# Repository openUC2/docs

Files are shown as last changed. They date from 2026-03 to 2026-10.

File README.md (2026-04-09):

# openUC2 Documentation

This repository is used to build and deploy openUC2's documentation site.

## Usage

People who are just end-users of openUC2 products & projects should go to [docs.openuc2.com](https://docs.openuc2.com).

Developers should view the current state of the [openUC2/docs](https://github.com/openUC2/docs) repo at [docs-dev.openuc2.com](https://docs-dev.openuc2.com).
That site should be treated as a developer preview which can have disruptive changes without any prior notice; thus, customers should not be sent to `docs-dev.openuc2.com`.

[docs-staging.openuc2.com](https://docs-staging.openuc2.com) should be used as an intermediate "beta preview" version of `docs.openuc2.com`: it is more stable (i.e. has less accidental disruption) compared to `docs-dev.openuc2.com`, but it may still have a few subtle problems which need to be discovered and fixed before the changes are generally exposed to all customers.
It's okay to link certain customers to certain pages in `docs-staging.openuc2.com`, but only if those customers need to have a preview of newer versions of those specific pages before those changes are ready to be made generally available at `docs.openuc2.com`.

For further explanation, please refer to [DN 17](https://www.notion.so/DN-17-Customer-facing-documentation-system-2854e612c78a80a3a1bdcc223bf030c0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).

## Development

### Local preview

Run:

```
npm install
npm run start
```

Then open: <http://localhost:3000>

## Deployment

The openUC2 docs site has three GitHub Pages deployments, each with its own repository:

- development/edge release channel: the `master` branch of [openUC2/docs](https://github.com/openUC2/docs); deploys to [docs-dev.openuc2.com](https://docs-dev.openuc2.com).
- staging/beta release channel: the `staging` branch of openUC2/docs; automatically mirrored to the `deploy` branch of [openUC2/docs-staging](https://github.com/openUC2/docs-staging), which deploys to [docs-staging.openuc2.com](https://docs-staging.openuc2.com)
- prod/stable release channel: the `prod` branch of openUC2/docs; automatically mirrored to the `deploy` branch of [openUC2/docs-prod](https://github.com/openUC2/docs-prod), which deploys to [docs.openuc2.com](https://docs.openuc2.com).

After cloning the openUC2/docs repo, then you can fast-forward your local `staging` and `prod` branches to the desired commits on your local `master` branch.
Then you can deploy changes to the staging and prod release channels by pushing your updated local `staging` and `prod` branches, respectively, up to the openUC2/docs repository.
The deployment process should usually be done as follows:

1. Fast-forward the `staging` branch of the openUC2/docs repo to whichever commit of the `master` branch that we want to publish.
2. Wait for it to build and deploy, then look at `docs-staging.openuc2.com` and fix any problems.
3. Once the version in the `docs-staging` repo is stable and mature enough for publication, fast-forward the `prod` branch of the openUC2/docs repo to the publication-ready commit of the `staging` branch.

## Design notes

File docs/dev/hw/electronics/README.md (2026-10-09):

# Electronics

Boards that run the UC2 ESP32 firmware (`uc2-ESP`). A host talks serial JSON to one board; boards talk CANopen to each other. Protocol, commands and Python clients: [Serial & CANopen interface](../../sw/interface/index.md).

UC2 control topologies

## Available hardware interfaces

| Board | Role | Firmware env | Page |
|---|---|---|---|
| Standalone board v3 / v4 (ESP32 DevKit) | standalone, no CAN | `UC2_3`, `UC2_4` | [Standalone board](./uc2-standalone-board/README.md) |
| Standalone board v4 | CAN master, node 1 (hybrid: motors local, LED/galvo via CAN) | `UC2_canopen_standalone_v4_release` | [Standalone board](./uc2-standalone-board/README.md) |
| HAT+ for Raspberry Pi 5 | CAN master, node 1 | `UC2_canopen_master` | [HAT+](./hat-plus/README.md): [v1](./hat-plus/v1/README.md), [v2](./hat-plus/v2/README.md) |
| Stepper backpack (XIAO ESP32-S3) | CAN satellite, motor A/X/Y/Z = node 10/11/12/13 | `UC2_canopen_slave_motor` | [Stepper backpack](./stepper-backpack/README.md) |
| Laser interface (XIAO ESP32-S3) | CAN satellite, node 20 | `UC2_canopen_slave_laser` | [FRAME electronics](./frame/README.md#laser-interface) |
| LED / illumination (XIAO) | CAN satellite, node 30 | `UC2_canopen_slave_led` | [Boards & node IDs](../../sw/interface/reference/boards-and-node-ids.md) |
| Galvo interface (XIAO) | CAN satellite, node 40 | `UC2_canopen_slave_galvo` | [Boards & node IDs](../../sw/interface/reference/boards-and-node-ids.md) |
| PS4 controller | Bluetooth on standalone builds, or CAN bridge node 5 (DS4 on USB-OTG) | `UC2_canopen_bridge_ps4_usbhost` | [PS4 controller](./ps4-controller/README.md) |

[FRAME electronics](./frame/README.md) is the design reference for the HAT+, stepper backpack Rev C, laser interface and pogo-pin connectors.

Every board also accepts serial JSON on its own USB port: 115200 baud on the standalone board, 921600 on the HAT+ ESP32, USB-CDC (baud ignored) on XIAO satellites.

## Bus

| Item | Value |
|---|---|
| Protocol | CANopen (CANopenNode), master = node 1 |
| Bitrate | 500 kbit/s, fixed |
| Connector | JST-XH 4, daisy-chained: **1 GND, 2 +12 V, 3 CAN_H, 4 CAN_L** |
| Transceiver | SN65HVD230 (3.3 V), not isolated |
| Termination | 120 Ω at the two physical ends of the bus only |

Termination solder jumpers, all open by default:

| Board | Jumper |
|---|---|
| HAT+ v2 | JP801 |
| HAT+ v1 | JP1001 |
| Stepper backpack | JP502 |
| Laser interface | JP301 |
| Galvo interface | JP2001 |

Pins, node IDs and routing per env: [Boards, roles & node IDs](../../sw/interface/reference/boards-and-node-ids.md). Adding a board to the bus: [Add a CAN satellite](../../sw/interface/how-to/add-can-satellite.md).

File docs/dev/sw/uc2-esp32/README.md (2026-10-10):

---
title: Firmware
---

# UC2-ESP32 Firmware

One firmware ([youseetoo/uc2-esp32](https://github.com/youseetoo/uc2-esp32), branch `main`) runs on every UC2 ESP32 board. Each board has its own PlatformIO environment that selects pins and modules at compile time. A build runs in one of three roles:

| Role | Example env | What it does |
|---|---|---|
| Standalone | `UC2_3`, `UC2_4` | JSON over USB serial, all devices on the board |
| CAN master | `UC2_canopen_master` (HAT+) | JSON over USB serial, routes each device locally or over CANopen to a satellite |
| CAN satellite | `UC2_canopen_slave_motor`, `_laser`, `_led`, … | executes commands from the master; still accepts JSON on its own USB port |

All envs, node IDs and baud rates: [Boards, roles & node IDs](../interface/reference/boards-and-node-ids.md).

## Where the code lives

| Path | Content |
|---|---|
| `platformio.ini` | one `[env:…]` per board, with `-D` feature flags |
| `main/config/<env>/PinConfig.h` | pins and defaults of that board |
| `main/src/<module>/` | controllers (`motor`, `home`, `laser`, `led`, `scanner`, `tmc`, `bt`, …), `serial/` (JSON parser, `Endpoints.h`), `canopen/` |

## Build and flash

- Prebuilt images: web flasher at [youseetoo.github.io/flasher.html](https://youseetoo.github.io/flasher.html) (Chrome or Edge, USB).
- From source: `pio run -e <env> -t upload`. Details: [Compiling from scratch](./08_Flashing_the_firmware.md).
- Satellites on a CAN bus can be updated through the master: [Update firmware over CAN](../interface/how-to/update-firmware-over-can.md).

## Talk to it

- [Serial & CANopen interface](../interface/index.md): overview and tutorials
- [Serial protocol](../interface/reference/serial-protocol.md): framing, `qid`, replies
- [Serial commands](../interface/reference/serial-commands.md): all endpoints with keys and examples

## Pages in this folder

- [Build environment](./01_Setup_Buildenvironment.md)
- [Firmware description](./02_UC2_Firmware_Description.md): architecture and modules
- [Controlling the UC2e](./07_Controling_the_ESP32.md): clients (Python, web, PS4, ImSwitch)
- [UC2Serial Android app](./07_Controlling_the_ESP32_APP.md)
- [Compiling from scratch](./08_Flashing_the_firmware.md)

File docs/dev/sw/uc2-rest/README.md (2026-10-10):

---
title: Hardware Control API
---

# UC2-REST Python API

:::warning Outdated
Most of the API shown here does not exist in `uc2rest`. Current documentation: [uc2rest reference](../interface/reference/python-uc2rest.md).
:::

Advanced documentation for the UC2-REST Python library, including API reference, integration guides, and custom development.

## Overview

UC2-REST is the Python interface library that provides high-level control of UC2 hardware through the UC2-ESP32 firmware. It serves as the bridge between Python applications (including ImSwitch) and the low-level hardware control.

## Key Features

- **Object-Oriented API**: Intuitive Python interface for hardware control
- **Dual Communication**: USB Serial and WiFi/HTTP support
- **Error Handling**: Robust communication with automatic retry
- **ImSwitch Integration**: Native support for ImSwitch microscopy software
- **Extensible**: Easy to add custom device managers and protocols

## Available Documentation

### Getting Started
- **Installation Guide** - Install UC2-REST library
- **Quick Start** - Basic usage examples
- **API Overview** - High-level API introduction

### Core Documentation
- **[Communication Introduction](./06_INTRO.md)** - Basic communication concepts
- **[ESP32 Messaging](./ESP32_Messaging_Callback.md)** - Message handling system
- **[Motor Control](./ESP32_Motor.md)** - Motor control examples
- **[Command Sending](./05_Sending_Commands.md)** - Command interface details

### Advanced Topics
- **API Reference** - Complete API documentation
- **Integration Guide** - Integrate with other software
- **Custom Managers** - Create custom device managers
- **Protocol Documentation** - Communication protocol details

## Quick Reference

### Basic Connection
```python
from UC2REST import UC2Client

# USB Serial connection
client = UC2Client(serialport="/dev/ttyUSB0")

# WiFi connection
client = UC2Client(host="192.168.1.100", port=31950)

# Check connection
if client.is_connected:
    print("Connected to UC2-ESP32")
```

### Hardware Control
```python
# LED control
client.led.set_led(channel=1, intensity=100)
client.led.set_led_array([100, 50, 75, 0])

# Motor control
client.stage.move_x(1000)
client.stage.move_xyz(x=500, y=500, z=100)
client.stage.home_xyz()

# Laser control
client.laser.set_laser(channel=1, intensity=50)
client.laser.turn_off_all()

# Sensor reading
sensors = client.sensor.get_sensor_data()
position = client.stage.get_position()
```

## Architecture

### Class Hierarchy
```
UC2Client
├── SerialManager (USB communication)
├── HTTPManager (WiFi communication)
├── LEDManager (LED control)
├── StageManager (Motor control)
├── LaserManager (Laser control)
├── SensorManager (Sensor reading)
└── StateManager (System status)
```

### Communication Flow
```
Python Application
      ↓
   UC2Client
      ↓
Communication Manager (Serial/HTTP)
      ↓
JSON Protocol
      ↓
UC2-ESP32 Firmware
      ↓
Hardware Components
```

## Device Managers

### LED Manager
```python
class LEDManager:
    def set_led(self, channel, intensity):
        """Set individual LED intensity"""

    def set_led_array(self, intensities):
        """Set multiple LED intensities"""

    def get_led_status(self):
        """Get current LED status"""
```

### Stage Manager
```python
class StageManager:
    def move_x(self, steps):
        """Move X axis by specified steps"""

    def move_xyz(self, x=0, y=0, z=0):
        """Move multiple axes simultaneously"""

    def set_position(self, x=None, y=None, z=None):
        """Set absolute position"""

    def home_xyz(self):
        """Home all axes"""

    def get_position(self):
        """Get current position"""
```

### Laser Manager
```python
class LaserManager:
    def set_laser(self, channel, intensity):
        """Set laser power"""

    def turn_off_all(self):
        """Emergency laser shutdown"""

    def get_laser_info(self):
        """Get laser capabilities"""
```

## Integration Examples

### ImSwitch Configuration
```json
{
  "rs232devices": {
    "ESP32": {
      "managerName": "ESP32Manager",
      "managerProperties": {
        "serialport": "/dev/ttyUSB0",
        "host_": "192.168.1.100"
      }
    }
  },
  "positioners": {
    "ESP32Stage": {
      "managerName": "ESP32StageManager",
      "managerProperties": {
        "rs232device": "ESP32"
      },
      "axes": ["X", "Y", "Z"],
      "forScanning": true
    }
  }
}
```

### Custom Device Manager
```python
from UC2REST import UC2Client
from imswitch.imcontrol.model.interfaces import DeviceManager

class CustomUC2Manager(DeviceManager):
    def __init__(self, deviceInfo, name, **kwargs):
        super().__init__(deviceInfo, name, **kwargs)

        # Initialize UC2-REST client
        self.client = UC2Client(
            serialport=deviceInfo.managerProperties.get("serialport"),
            host=deviceInfo.managerProperties.get("host"),
        )

    def custom_function(self, parameters):
        """Implement custom functionality"""
        return self.client.send_command(
            {"task": "/custom_act", "parameters": parameters}
        )
```

### Jupyter Notebook Integration
```python
# Interactive microscopy control
import ipywidgets as widgets
from IPython.display import display

def create_motor_controls(client):
    """Create interactive motor controls"""

    # Movement buttons
    move_x_plus = widgets.Button(description="X+")
    move_x_minus = widgets.Button(description="X-")

    # Step size slider
    step_size = widgets.IntSlider(value=100, min=10, max=1000)

    def on_move_x_plus(b):
        client.stage.move_x(step_size.value)

    def on_move_x_minus(b):
        client.stage.move_x(-step_size.value)

    move_x_plus.on_click(on_move_x_plus)
    move_x_minus.on_click(on_move_x_minus)

    return widgets.VBox([step_size, widgets.HBox([move_x_minus, move_x_plus])])

# Create and display controls
controls = create_motor_controls(client)
display(controls)
```

## Advanced Usage

### Error Handling
```python
from UC2REST import UC2RESTError
import serial

try:
    client = UC2Client(serialport="/dev/ttyUSB0")
    client.stage.move_x(1000)

except UC2RESTError as e:
    print(f"UC2-REST error: {e}")

except serial.SerialException as e:
    print(f"Serial communication error: {e}")

except Exception as e:
    print(f"Unexpected error: {e}")
```

### Custom Commands
```python
def send_custom_command(client, command_data):
    """Send custom JSON command"""
    try:
        response = client.send_command(command_data)

        if response.get("return") == 1:
            return response
        else:
            raise UC2RESTError(f"Command failed: {response}")

    except Exception as e:
        print(f"Communication error: {e}")
        return None

# Example usage
result = send_custom_command(
    client, {"task": "/custom_task", "parameter1": "value1", "parameter2": 42}
)
```

### Performance Optimization
```python
class OptimizedController:
    def __init__(self, client):
        self.client = client
        self.position_cache = {"x": 0, "y": 0, "z": 0}

    def move_relative(self, dx=0, dy=0, dz=0):
        """Move relative with position caching"""
        # Update cached position
        self.position_cache["x"] += dx
        self.position_cache["y"] += dy
        self.position_cache["z"] += dz

        # Send movement command
        self.client.stage.move_xyz(x=dx, y=dy, z=dz)

    def get_cached_position(self):
        """Get position from cache (faster than querying hardware)"""
        return self.position_cache.copy()

    def sync_position(self):
        """Synchronize cache with actual hardware position"""
        actual_pos = self.client.stage.get_position()
        self.position_cache.update(actual_pos)
        return actual_pos
```

## Custom Protocol Development

### Protocol Extension
```python
class CustomProtocol:
    def __init__(self, client):
        self.client = client

    def batch_commands(self, commands):
        """Execute multiple commands efficiently"""
        batch_command = {"task": "/batch_act", "commands": commands}
        return self.client.send_command(batch_command)

    def stream_data(self, duration, interval):
        """Stream sensor data for specified duration"""
        stream_command = {
            "task": "/stream_start",
            "duration": duration,
            "interval": interval,
        }

        # Start streaming
        response = self.client.send_command(stream_command)

        if response.get("return") == 1:
            # Read streamed data
            data = []
            for _ in range(int(duration / interval)):
                reading = self.client.sensor.get_sensor_data()
                data.append(reading)
                time.sleep(interval)

            return data
        else:
            raise UC2RESTError("Failed to start data streaming")
```

## Testing and Validation

### Unit Tests
```python
import unittest
from UC2REST import UC2Client

class TestUC2REST(unittest.TestCase):
    def setUp(self):
        self.client = UC2Client(serialport="/dev/ttyUSB0")

    def test_connection(self):
        """Test basic connection"""
        self.assertTrue(self.client.is_connected)

    def test_led_control(self):
        """Test LED control"""
        # Turn LED on
        self.client.led.set_led(channel=1, intensity=100)

        # Turn LED off
        self.client.led.set_led(channel=1, intensity=0)

        # Test should not raise exceptions
        self.assertTrue(True)

    def test_stage_movement(self):
        """Test stage movement"""
        original_pos = self.client.stage.get_position()

        # Move and return
        self.client.stage.move_x(100)
        time.sleep(1)
        self.client.stage.move_x(-100)
        time.sleep(1)

        final_pos = self.client.stage.get_position()

        # Should return to approximately original position
        self.assertAlmostEqual(original_pos["x"], final_pos["x"], delta=10)

if __name__ == "__main__":
    unittest.main()
```

### Performance Benchmarks
```python
import time
import statistics

def benchmark_communication_speed(client, n_commands=100):
    """Benchmark communication speed"""
    times = []

    for _ in range(n_commands):
        start = time.time()
        client.state.get_state()
        end = time.time()
        times.append(end - start)

    return {
        "mean": statistics.mean(times),
        "median": statistics.median(times),
        "stdev": statistics.stdev(times),
        "commands_per_second": 1.0 / statistics.mean(times),
    }

# Run benchmark
results = benchmark_communication_speed(client)
print(f"Communication speed: {results['commands_per_second']:.1f} commands/sec")
```

## Troubleshooting

### Common Issues

**Connection Problems**:
```python
# Check available serial ports
import serial.tools.list_ports

ports = serial.tools.list_ports.comports()
for port in ports:
    print(f"{port.device}: {port.description}")

# Test with different parameters
try:
    client = UC2Client(serialport="/dev/ttyUSB0", baudrate=115200, timeout=2.0)
except Exception as e:
    print(f"Connection failed: {e}")
```

**Communication Timeouts**:
```python
# Increase timeout for slow operations
client = UC2Client(serialport="/dev/ttyUSB0", timeout=5.0)

# Implement retry logic
def robust_command(client, command_func, max_retries=3):
    for attempt in range(max_retries):
        try:
            return command_func()
        except Exception as e:
            if attempt == max_retries - 1:
                raise e
            time.sleep(1)
```

**Debug Mode**:
```python
# Enable debug output
client = UC2Client(serialport="/dev/ttyUSB0", DEBUG=True)

# All communication will be logged
client.stage.move_x(1000)
# Output: [DEBUG] Sending: {"task": "/motor_act", ...}
#         [DEBUG] Received: {"return": 1, ...}
```

## Contributing

### Development Setup
```bash
# Clone repository
git clone https://github.com/openUC2/UC2-REST
cd UC2-REST

# Install in development mode
pip install -e .

# Install development dependencies
pip install -r requirements-dev.txt
```

### Code Style
- Follow PEP 8 style guidelines
- Use type hints where possible
- Document all public methods
- Include docstring examples

### Testing
```bash
# Run unit tests
python -m pytest tests/

# Run with coverage
python -m pytest --cov=UC2REST tests/

# Run integration tests (requires hardware)
python -m pytest tests/integration/
```

## Related Resources

- **[UC2-ESP32 Firmware](../uc2-esp32/README.md)** - Firmware documentation
- **[ImSwitch Integration](../imswitch/Advanced/02_Usage/UC2-REST.md)** - ImSwitch usage guide
- **[Hardware Interfaces](../../hw/electronics/README.md#available-hardware-interfaces)** - Hardware components

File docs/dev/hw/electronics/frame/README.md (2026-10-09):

# FRAME

Development repository for electronic parts of the mAIkroscope (formerly fiveD/XYZ)

## CANBUS as communication between devices

CANBUS is a differential bus where many devices are connected to the same CAN_H and CAN_L wires, then can communicate with each other.

The electrical functionality requires a dedicated CAN transceiver chip for every device connecting to the bus. The receiver converts differential signaling on the bus to input and output interfaces, while providing tolerance to voltages of commonly 20V on the CAN_H/CAN-L and isolating faulty voltages from reaching to the GPIOs of connected controllers.

The two wires of CANBUS need to be connected together with two 120 Ohm resistors at opposite ends. This termination is like impedance matching and prevents the signals to reflect back from a far end of the bus wires. The terminators should be placed on the ends that are farthest apart, and can probably be integrated on PCBs of the devices that are farthest apart. The "backbone" with the termination on both ends should be much longer than the taps ("stubs") from the backbone to the devices. The physical wires, electrical specs (like differential signaling and voltage levels) are OSI layer 1.

CAN message collision avoidance is done in a CAN controller. This is available as a separate chip (with SPI interface), but it is also integrated as peripheral in the ESP32. At the start of each frame, every device wanting to send something starts sending their CAN ID (programmed into the device, must be unique). If a device has a lower ID, it gets priority by sending a dominant bit (logical 0, CAN_H and CAN_L are driven to different voltage levels) where other devices send a logical 1 (recessive bit, CAN_H and CAN_L are not driven making them return to equal voltage). If a device with a higher ID gets overruled this way, it will listen in this frame cycle and waits for the next frame to start before attempting to transmit its ID again. The frames also contain set amount of data and error checking bits.

There are frame types to request data (Remote frame), data containing (data frame), errror frame (when error is detected) and overload frame (indicating delay between data or remote frames is needed).

That is Link Layer (OSI layer 2).

OSI Layers 1 and 2 as implemented are standardized with ISO 11898-1.

ESP32 calls their implementation of this and maybe higher OSI layers TWAI: [ESP-IDF TWAI Docs](https://docs.espressif.com/projects/esp-idf/en/v4.2.1/esp32/api-reference/peripherals/twai.html)

ESP32 CAN controller is not compatible with CAN FD (flexible data-rate), just classical CAN with 11-bit IDs (Standard Frame Format) and 29-bit IDs (Extended Frame Format).

The ESP32 TWAI controller depends on getting a receiving signal at the same time that it is sending something in order to work, because that is how it can determine if it is allowed to talk (CAN ID arbitration/priorities).

UC2 runs CANopen (CANopenNode) on top at 500 kbit/s, with the ESP32 master as node 1 and satellites as slaves: [Architecture](../../../sw/interface/explanation/architecture.md), [Boards, roles & node IDs](../../../sw/interface/reference/boards-and-node-ids.md).

## hatplus-for-raspberrypi-5

- [HAT schematic PDF (Rev D)](../hat-plus/v1/schematic.pdf)
- <a href={require("../hat-plus/v2/ibom-hatv2.html")} target="_blank">v2 HAT ibom HTML</a>

This board is effectively the mainboard for the mAIkroscope. It contains DC power input for the whole machine, switched power transmission to all motors, main coordinating microcontroller and interfacing with a Raspberry Pi.

The HAT is put on top of a Raspberry Pi 5 and can supply it with 5.1V 5A through the 40-pin header. The HAT will also fit on a NVIDIA Jetson development board, because its 40-pin header is designed to be compatible with Raspberry Pi's.

There are many comments for design choices, mechanisms, failsafes and links to external ressources in the [HAT schematic PDF](../hat-plus/v1/schematic.pdf).

The microcontroller is a ESP32-WROOM-32E-N8 module with integrated PCB antenna, 8 MB flash. The used ESP32-D0WD-V3 chip in the module has 449 KB ROM, 520 KB SRAM and 16 KB SRAM in RTC core.

### Raspberry Pi HAT+ implementation (EEPROMS, HAT+ spec)

Our HAT is designed to comply with [Raspberry Pi HAT+ specifications](https://datasheets.raspberrypi.com/hat/hat-plus-specification.pdf).

However, it has the function of 2 types of HAT+s: Power supply and using the GPIO header for data exchange purposes.

The I2C addresses of EEPROMS on the HAT indicate the HAT+ class to the Raspberry Pi firmware. In multiple HAT+ stacked on one Raspberry Pi, there can be only one HAT of each class per spec and to avoid I2C address collisions.

The HAT has 2 EEPROM chips with functions and content:

| I2C Address | HAT+ class meaning | EEPROM contents |
| --- | --- | --- |
| 0x1010_000  | Standard (uses GPIO for data) | tbd |
| 0x1010_000  | Power: MODE1 (can deliver 5A) | tbd |

The content of the HAT can be custom content like serial numbers, manufacturer, or drivers/instructions for the Raspberry Pi OS on how to interface with the HAT. The format and mandatory fields are in the Raspberry Pi HAT+ spec document.

For our HAT, it would make sense to fill the EEPROMS for these functions:

- Ensure that the full power for USB devices is automatically activated (implementing a MODE1 HAT+).
- Add our company name, product name, board revision, unique serial number that we keep track of in the company
- Driver or interface/pin description to make the SPI CAN controller chip (MCP2515) available to python scripts via Linux.
- Descriptions of other GPIO pin functions, to be able to use them abstractly in future scripts: buspower_EN, ESP32 interface UART and flashing, etc
- Maybe things like hardware configuration options that should "just work", like what features and modules the mAIkroscope model has that it is built into, and factory calibration data for its modules

### Raspberry Pi pinout

For Raspberry Pi pin numbering and assignable or fixed functions, see [pinout.xyz](https://pinout.xyz).

In the table is the physical/board pin number, not GPIO number. The pin numbering on the header is odd-even.

| RPi | Function |
| --- | --- |
| 3 | I2C-1_SDA connectable to ESP and XH_5V+I2C via solderjumper JP101  |
| 5 | I2C-1_SCL connectable to ESP and  XH_5V+I2C via solderjumper JP102 |
| 8 | UART_TX to ESP, 921600 baud (parallel with USB-UART TX) |
| 10  | UART_RX from ESP (parallel with USB-UART RX) |
| 11  | ESP Auto-program circuit RTS |
| 16  | buspower-off when HI |
| 19  | CAN-Controller SPI PICO |
| 21  | CAN-Controller SPI POCI |
| 23  | CAN-Controller SPI SCK |
| 24  | CAN-Controller SPI CS |
| 26  | EEPROM I2C SCL (GPIO7; the HAT+ spec puts ID_SC on pin 28) |
| 27  | EEPROM I2C SDA (ID_SD, GPIO0) |
| 32  | CAN-Controller Interrupt |
| 36  | ESP Auto-program circuit DTR |

### ESP32 pinout

Actual chosen model is ESP32-WROOM-32E-N8.

It runs the CAN master firmware (env `UC2_canopen_master`, node 1, serial 921600 baud). It is programmable via the USB-C port and CP2102 USB-Serial chip, or via Raspberry Pi UART (manual press of BOOT and RST necessary, or programming of the 2 Raspberry Pi GPIO to use the Auto-program circuit).

In the table are only GPIOs that are used and notable for the HAT. All GPIOs are also available at testpoints.

| GPIO | Function |
| ---- | --- |
| 4 | Buspower_off when HI |
| 17 | CAN/TWAI TX (send) |
| 18 | CAN/TWAI RX (receive) |
| 19 | Neopixel LED data |
| 21 | I2C-1_SDA to XH_5V+I2C connector and solderjumpable to Raspi |
| 22 | I2C-1_SCL to XH_5V+I2C connector and solderjumpable to Raspi |
| 27 | Camera-IO-interface Cam In Line 0 |
| 32 | Camera-IO-interface Cam Out Line 1 |
| 33 | Camera-IO-interface Cam In/Out Line 2 |

### Emergency STOP connector

There is a 3.5 mm TRS connector (stereo headphones) to connect an external box with a Emergency-STOP button and LEDs (optional). It is J501 and oriented out the back of the mAIkroscope.

A STOP button should be normally closed, and should open and lock when pressed. This button should be connected between Tip and Ring of the TRS connector. This button is required for Buspower (5V or 12V out of the respective XH jacks) to turn on.

LEDs can be placed in or on the external box so it is easily visible in dark conditions. The LEDs have a budget of 3.3V and 20 mA, and resistors should be included in the box. If more amperage is pulled, the HAT may recognize it as STOP button press. Connect LEDs with High side at Tip and Low side at Sleeve of TRS connector. LEDs will always be lit regardless of STOP button state.

### HAT: Terminating CANBUS or activating CAN activity indicator LED

Close JP jumpers by making a solder bridge between the 2 pads. To open a NO (normally open) solderjumper again, wipe, wick or suck away the solder bridge. To open a NC (normally closed) solderjumper, cut the trace between the pads with a knife very carefully and not cutting too deep. Design flaw: Cutting too deep exposes the copper of the inner layers and may cut or short traces on the inner layers. The cut should be planned in the PCB editor, and the trench should be cleaned up and filled with solder mask after cutting. In future, use 0-Ohm resistors for NC.

| Operation | Effect |
| --- | --- |
| Close JP1001 | Terminates CANBUS on the board by connecting CAN_H and CAN_L through 120 Ohm resistor (v2: JP801) |
| Close JP1002 | Red LED D1001 lights when CAN bus is in dominant state (logical 0, lines at different voltages) (v2: JP802) |

### Disabling communication or power-switching functions

This is only relevant for troubleshooting and may defeat safety functions.

| Operation | Effect |
| --- | --- |
| Close JP201 | ESP and Raspberry Pi can no longer turn off buspower via GPIO pin |
| Close JP601 | Override all buspower-off sources including Emergency-STOP button. Button SW601 can still momentary turn-off buspower. |
| Open JP901  | Disconnect Raspberry pin from RTS line of CP2102 and Auto-program circuit |
| Open JP902  | Disconnect Raspberry pin from DTR line of CP2102 and Auto-program circuit |

## stepper-backpack

Schematic PDF: `kicad/stepper-backpack/OUTPUTS/for-humans/stepper-backpack.pdf`

ibom HTML: `kicad/stepper-backpack/OUTPUTS/for-humans/ibom.html`

stepper-backpack is a PCB to fasten to the back of a NEMA 11 stepper motor. It enables the motor-PCB-assembly to be controlled via CAN with high-level commands and implements absolute feedback.

- Glue a circular magnet to the end of the stepper motor's axle
- Mount the PCB to the back of the motor using 3 pcs of M2.5 screws with cylindrical standoffs between board and motor. The standoffs should be about 2.5mm long. The PCB should fit completely behind the motor.
- Connect the motor's electrical connections (coils) to the PCB via screw terminal blocks. A and B labels correspond to the 2 coils in the motor.
- Connect it to a 12V supply and CAN via JST XH 4-pin connector (1 GND, 2 +12 V, 3 CAN_H, 4 CAN_L)
- Firmware env `UC2_canopen_slave_motor`; default node 11, CI builds `_motA/_motX/_motY/_motZ` = nodes 10/11/12/13 (details: [Stepper backpack](../stepper-backpack/README.md))
- The PCB controls the motor with a TMC2209 stepper motor driver
- A magnetometer on the PCB measures axle position and supply feedback for accurate positioning
- A XIAO ESP32S3 plugged in to the PCB can accept high-level commands (go to a position) and handle autonomous homing and stepping control (low level control of the stepper motor driver)
- The high-level interface can supply information about motor load, command success/status, fail state, etc.
- Endstop can be connected to a XIAO pin, 3.3V and GND with JST ZH 3-pin connector.

### Pinout

The different XIAO models connect to different ESP GPIOs, and strapping pins, pins with glitches or pins with default pullups/pulldowns may be different between ESP models in the XIAO format.

| XIAO pin | Function |
| --- | --- |
| D0 | Endstop |
| D1 | CAN Receive / SCL on old bus |
| D2 | CAN Send / SDA on old bus |
| D3 | Motor driver DIAG output |
| D4 | I2C SDA to encoder |
| D5 | I2C SCL to encoder |
| D6 | UART send to motor driver |
| D7 | UART recv from motor driver  |
| D8 | Motor direction |
| D9 | Motor step |
| D10 | Motor driver enable |

### Current sensing and current setting

Rsense (or R_SENSE) is __0.2 Ohm__. This is the value of the sense resistance connected to BRA and BRB of the TMC2209.

The current limit can be set by setting the __Vsense__ value in the TMC, which is the sensitivity of the current measurement. Setting this, with the 0.2 Ohms of actual resistance on stepper-backpacker, yields:

- Vsense=0 (low sensitivity curr sense setting): 1.4A peak, 1A RMS
- Vsense=1: 0.8A peak, 0.55A RMS

### Converting Rev. C from 12V+CAN to 5V+I2C

Make sure there are pullups (4.7k) to 3.3V somewhere on both I2C lines.

Use the ibom.html to find the correct solderjumpers on the board.

Close JP jumpers by making a solder bridge between the 2 pads. Open R 0-resistors by unsoldering them or snapping them with pliers.

| Operation | Effect |
| --- | --- |
| Close JP102 | CANBUS_P connects directly to XIAO GPIO (as I2C-1_SDA) |
| Close JP103 | CANBUS_N connects directly to XIAO GPIO (as I2C1_SCL) |
| Close JP501 | Connects CAN transceiver Rs to 3.3V to STBY transmitter driver |
| Open R502 | Disconnect still-active CAN receiver oupoutput from XIAO pin D1 |
| Open R501 | Disconnects CAN transceiver VCC power input from 3.3V |
| Close JP101 | Connects 12V and 5V power nets (Warning: Do not connect 12V when closed) |

### Terminating CANBUS or activating CAN activity indicator LED

| Operation | Effect |
| --- | --- |
| Close JP502 | Terminates CANBUS on the board by connecting CAN_H and CAN_L through 120 Ohm resistor |
| Close JP503 | Red LED D501 lights when CAN bus is in dominant state (logical 0, lines at different voltages) |

## Laser-interface

This board can control a laser or LEDs and has 4 channels. It connects to the XH_12V+CAN backbone, has a XIAO to accept CAN commands and generate PWM signals, and has connectors for interlock sources. The interface to the laser is 4x PWM signal between 0V and 3.3V (LO should mean off), and 12V power.

Firmware env `UC2_canopen_slave_laser`, default node 20; laser channels 0–3 map to OD sub-index 1–4.

### XIAO pinout

I is intended as input to the XIAO. O is intended as output.

| XIAO pin | XIAO ESP32S3 pin | Board Function |
| --- | --- | --- |
| D0 | GPIO_01 | I: LO when interlock tripped (enable pullup), O: pull LO to light keyswitch-LED |
| D1 | GPIO_02 | O: signal_1 |
| D2 | GPIO_03 | O: signal_2 |
| D3 | GPIO_04 | O: CAN-SEND |
| D4 | GPIO_05 | O: signal_3 |
| D5 | GPIO_06 | O: signal_4 |
| D6 | U0TXD/GPIO_43 | Unused, available on J1101 |
| D7 | U0RXD/GPIO_44 | Unused, available on J1101 |
| D8 | GPIO_07 | Unused, available on J1101 |
| D9 | GPIO_08 | I: LO when interlock has power (keyswitch in ON position) |
| D10 | GPIO_09 | I: CAN-RECV |

### Keyswitch specifications and connections

J102 is a 3-pin screw terminal to connect a key-switch and a red LED.

The key-switch should be a single-pole single-throw key-operated switch where the key can only be removed in OFF position. It switches less than 1 mA at 3.3V. In the ON position, the switch should connect pin 2 and 3 of J102.

The LED indicates when the interlock has triggered and the user needs to reset the interlock by turning off and on the keyswitch. It has 200 Ohms in series at 3.3V, so a red LED will be driven with around 7 mA. An ESP GPIO can light this LED at half current. The red LED on the board close to the output terminal has the same states as the external LED. An LED should directly be connected to J102 with Anode (+) on pin 2, and Cathode (-) on pin 1.

### Interlock

The interlocks ensure that a signal can only pass from the ESP to the laser if:

- The keyswitch is in the ON position
- 12V power is stable (aka Emergency-stop not pushed)
- A magnet switch is closed indicating that something like a laser-safety hood is covering the device
- An endstop or optical endstop is pressed indicating that the modules are fully inserted, the hood is closed, etc.

#### Interlock behavior and status inticators

The interlock has to be powered on by turning the keyswitch ON. It will then watch all the interlock sources, and trigger if one of the sources has an unsafe state.

If the interlock has been triggered, it will stop transmitting any signal to the laser, and the red LED by the keyswitch and by the output terminals will be lit. The interlock will stay triggered until it is reset by turning the keyswitch OFF and ON again.

If the interlock is active and not triggered, signals from the ESP (signal_1-4) will be transmitted to the output terminal block. Probably only binary signals like PWM will work. If the interlock is transmitting, the green LED by the output terminals will be lit, but the red LED next to it will not be lit.

#### Interlock sources

__Keyswitch (J102)__: The keyswitch switches power to the latch circuit of the signals interlock. If this is ON, the green LED close to the output terminals will be lit.

__12V-OK (internal)__: The 12V input has to stay above 11.3V. If power falls below that, the 12V power to the laser will be turned off, and the interlock for the signals will be triggered. This enables early detection when the Emergency Stop has been pressed and the power is interrupted. When the 12V to the laser is ON, the green LED below the XIAO will be lit.

__Endstop (J103)__: The 3-pin screw terminal J103 provides GND, signal, and 3.3V. The signal has to be HI for normal operation, like when the modules are fully inserted or when the safety hood is closed. If the signal pin is LO or floating, it will trigger the interlock. Because there is constant 3.3V and GND available, optical endstops can be used.

__Magnet Switch (J104)__: On the 2-pin screw terminal J104, a simple magnet switch (reed switch) or other simple switch can be connected. The switch should close in the presence of a magnet, and be open otherwise. For normal operation, a magnet can be fixed to the safety hood, and the switch in the base where the magnet will be close if the hood is closed (safe). Other switches can also be used. When the contacts are closed (shorted), it is safe, and when the switch is opened, the interlock triggers.

#### Interlock overrides

Parts of the interlock can be deactivated so that no condition at this interlock source will trigger the interlock. This way, the laser-interface can be configured to the types of safety devices available, when it is integrated into a microscope.

To override parts of the interlock, turn on one or multiple switches inside the dipswitch __SW701__ to the side labeled ON. This will close the switch and assume SAFE regardless of the actual state of the interlock source. No state on the respective interlock source will trigger the interlock.

The individual switches of the dipswitch are numbered. All interlock sources are active if all switches are OFF (set to the side opposite of the side labeled ON).

| SW701 switch number | effect when ON |
| --- | --- |
| 1 | Magnet switch J104 overridden |
| 2 | 12V-OK interlock triggering overridden and 12V output to laser always ON |
| 3 | Hood Endstop switch J103 overridden |
| 4 | Overrides whole interlock including keyswitch. Signals will always be passed, but 12V-OK still switches laser power |

### Solderjumpers

| Operation | Effect |
| --- | --- |
| Close JP301  | Terminates CANBUS on the board by connecting CAN_H and CAN_L through 120 Ohm resistor |
| Close JP302  | Red CAN LED lights when CAN bus is in dominant state (logical 0, lines at different voltages) |
| Close JP1101 | Add 4.7k pullup on D6 |
| Close JP1102 | Add 4.7k pullup on D7 |
| Close JP1103 | Add 4.7k pullup on D8 |

### Using the board as CAN-to-GPIO converter

J1101 is a 9-pin screw terminal connected to the ESP/XIAO pins (before the interlocks), 12V and GND. The 12V is not switched. Signals 1-4 have always-connected pulldown resistors, D6-D8 have optional pullup resistors that can be enabled by closing solderjumpers.

| Screw terminal pin | connection  | pullup/pulldown |
| --- | --- | --- |
| 1 | GND | |
| 2 | 12V | |
| 3 | D1/signal_1 | down 4.7k |
| 4 | D2/signal_2 | down 4.7k |
| 5 | D4/signal_3 | down 4.7k |
| 6 | D5/signal_4 | down 4.7k |
| 7 | D6 | up 4.7k when closing JP1101 |
| 8 | D7 | up 4.7k when closing JP1102 |
| 9 | D8 | up 4.7k when closing JP1103 |

## Pogopin-connectors

Pogo pins are spring-loaded contacts. They will enable a module to automatically make electrical connections to the mainboard when it is inserted into the microscope.

- The boards have to be worked on in pairs so that the pins (M) align with the contact pads (F) and have the expected pinout.
- The boards need to be pressed and held together for the pins to make proper contact. The datasheet of the used pins specifies their optimal/minimum/maximum depress distance and spring force.
- The pogo pins have a current capibility of 1A per pin. For power transmission 12V is used over the pins and converted down (DC-DC converter) on the board with the device that needs it.
- In the original design I2C was passed via the pins, with the module as I2C peripheral of the mainboard. Current satellites use CAN instead, on JST-XH 4: GND, +12 V, CAN_H, CAN_L.
- The pogo pins can break off easily if the tips experience force to the sides. The pins should therefore be protected.  They can be placed in the part inside the microscope protected from touching. The connector part with the pads can be on the outside of the modules.
- The connector boards use XH wire-to-board connectors of the same type as the stepper backpack's bus connector (I2C-era pinout: GND, 12V, SDA, SCL).

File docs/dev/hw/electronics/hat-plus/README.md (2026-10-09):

---
sidebar_position: 20
---

# HAT+

12 V power and CAN master board for the Raspberry Pi 5. An ESP32 on the HAT runs the CAN master firmware; the Pi talks to it over serial, or joins the CAN bus itself through an MCP2515.

| | [v1](./v1/README.md) | [v2 (Rev D)](./v2/README.md) |
|---|---|---|
| ESP32 | ESP32-WROOM-32E | ESP32-WROOM-32E |
| ESP32 CAN TX / RX | GPIO17 / GPIO18 | GPIO17 / GPIO18 |
| Pi-side CAN | MCP2515 on SPI0 CE0, INT GPIO12 | MCP2515 on SPI0 CE0, INT GPIO12, 12 MHz crystal |
| CAN termination jumper | JP1001 | JP801 |
| CAN activity LED jumper | JP1002 | JP802 |
| Bus power off | ESP32 GPIO4, Pi GPIO23 (pin 16), E-stop | same, plus E-stop sense on ESP32 GPIO34 |
| Sensors | – | INA226 (0x46), 2× TMP102 (0x4A, 0x4B) |
| Bus connector | JST-XH 4 "12V+CAN" (plus a "5V+I2C" XH) | J102, JST-XH 4: 1 GND, 2 +12 V switched, 3 CAN_H, 4 CAN_L |

Both run the firmware env `UC2_canopen_master`: CAN master, node 1, serial 921600 baud via USB-C (CP2102) or the Pi UART (pins 8/10).

- Bus, pins and node IDs: [Boards, roles & node IDs](../../../sw/interface/reference/boards-and-node-ids.md)
- Using the bus from Linux: [CANopen from the Raspberry Pi](../../../sw/interface/tutorials/canopen-from-raspberry-pi.md)
- Design notes (power, E-stop, EEPROMs, jumpers): [FRAME electronics](../frame/README.md)

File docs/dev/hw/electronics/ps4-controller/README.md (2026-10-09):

# PS4 Controller

The PS4 controller provides intuitive wireless control of your UC2 microscope system, enabling hands-free operation of stages, focus, illumination, and scanning functions.

## Overview

Using Bluetooth connectivity, the PS4 controller connects to the ESP32-based UC2 board to provide comprehensive control over all microscope functions. This allows you to operate your microscope without touching it, reducing vibrations and improving imaging quality.

## Controller Mapping

### Stage Movement
- **Left Analog Stick (X-axis):** X Stage Movement (left/right)
- **Left Analog Stick (Y-axis):** Y Stage Movement (up/down)
- **Right Analog Stick (Y-axis):** Z Stage Movement - Coarse focusing
- **D-Pad:** Fine position adjustments in X and Y

### Focus Control
- **L2 Button:** Coarse Z Stage Decrement (focus down)
- **R2 Button:** Coarse Z Stage Increment (focus up)
- **R3 (Right Stick Click):** Enter Fine Focus Adjustment Mode

### Illumination Control
- **L1 Button:** Decrease LED/Laser Intensity
- **R1 Button:** Increase LED/Laser Intensity
- **Circle Button:** Toggle Illumination on/off
- **Triangle Button:** Switch Fluorescent Channel

### Scanning Functions
- **X Button:** Start/Stop Scan
- **Square Button:** Save Current Position
- **L3 (Left Stick Click):** Engage Auto-Scan Mode

### System Functions
- **Options Button:** Open Settings Menu
- **Share Button:** Log/Export Scan Data
- **PS Button:** System Power Toggle
- **Touchpad Button:** Reset Stage Position/Center

## Setup Instructions

### Requirements
- PS4 DualShock Controller
- UC2 ESP32 Standalone Board
- Chrome browser for firmware flashing
- UC2 firmware with PS4 controller support

### Installation Steps

1. **Flash Firmware:** Use the UC2 webserial flashing tool at https://youseetoo.github.io/
2. **Pair Controller:** Start the Bluetooth scan on the serial port (115200 baud), then put the controller into pairing mode (details in the tutorial):

   ```json
   {"task":"/bt_scan"}
   ```
3. **Test Functions:** Verify all button mappings work correctly
4. **Calibrate Movement:** Adjust motor speeds and step sizes as needed

## Applications

- Vibration-free microscope operation
- Hands-free focusing during live imaging
- Quick adjustments during time-lapse experiments
- Teaching demonstrations without touching equipment
- Remote operation during sensitive experiments

## Advantages

- **Reduced Vibrations:** No physical contact with microscope
- **Intuitive Control:** Familiar gaming controller interface
- **Wireless Freedom:** Operate from a comfortable distance
- **Multiple Functions:** Access all features without menus
- **Fast Adjustments:** Analog sticks for smooth, continuous movement

Perfect for anyone who wants intuitive, wireless control of their automated microscopy system!

For detailed setup instructions, see the [PS4 Controller tutorial](./01-PS4-Controller.md).

**CAN systems (FRAME / HAT+):** a DualShock 4 can also be plugged in by USB to a XIAO ESP32-S3 running the env `UC2_canopen_bridge_ps4_usbhost` (CAN bridge, node 5), which sends its commands to the satellites over CAN. See [Boards, roles & node IDs](../../../sw/interface/reference/boards-and-node-ids.md).

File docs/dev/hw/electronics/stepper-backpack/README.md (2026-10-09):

---
title: Stepper Motor Backpack
sidebar_position: 100
---

# Stepper Motor Controller with Rotational Encoder (TMC2209 + AS5600)





## **Overview:**
This motor controller is designed to control a stepper motor using the TMC2209 driver with optional feedback from a rotational encoder (AS5600). The XIAO ESP32-S3 handles communication and control.

| Interface | Current (CAN) revision |
|---|---|
| Firmware env | `UC2_canopen_slave_motor` (CAN satellite) |
| Node ID | default 11; CI builds `_motA` / `_motX` / `_motY` / `_motZ` = 10 / 11 / 12 / 13 |
| CAN | 500 kbit/s, CANopen; TX = D2 (GPIO3), RX = D1 (GPIO2) |
| Bus connector | JST-XH 4: 1 GND, 2 +12 V, 3 CAN_H, 4 CAN_L |
| Termination | JP502, 120 Ω, open by default; close only at a bus end |
| Serial | native USB-CDC of the XIAO, serial JSON (for testing without a bus) |

Node IDs, routing and the other satellites: [Boards, roles & node IDs](../../../sw/interface/reference/boards-and-node-ids.md). Flashing, setting the node ID and wiring: [Add a CAN satellite](../../../sw/interface/how-to/add-can-satellite.md). Older revisions talked I2C to the master over D1/D2 (SCL/SDA).

## **Components:**
- **TMC2209 Stepper Driver:** Manages the stepper motor's power and movement. It offers features like StallGuard for homing without limit switches.
- **AS5600 Encoder:** A magnetic encoder that tracks the stepper motor’s rotational position. Connected via I2C, it provides high-precision feedback for motor positioning.

## **Pin Descriptions:**
- **DIR (Direction):** Controls the rotational direction of the stepper motor (Clockwise/Counter-Clockwise). Controlled via **D8**.
- **STEP (Step Pulse):** Sends pulses to the motor for each step. Controlled via **D9**.
- **EN (Enable):** **D10**.
- **UART (TX/RX):** The XIAO communicates with the TMC2209 driver for advanced functions such as StallGuard and diagnostics via UART on **D6** (send) and **D7** (receive).
- **I2C (SDA/SCL):** Connects the XIAO to the encoder. I2C pins on the XIAO are **D4** (SDA) and **D5** (SCL).

## **Power Requirements:**
- **12V Input** (JST-XH bus connector, pin 2): Powers the motor and is regulated to 5V and 3.3V via a DC-DC converter for the motor driver and encoder.
- **5V Input** (old 5V+I2C revision only): The XIAO uses its internal regulator to supply 3.3V to the other components.

## **Features:**
- **StallGuard Functionality:** This feature detects motor stall conditions and is useful for homing operations without mechanical limit switches.
- **I2C Encoder (AS5600):** Provides high-precision feedback on motor position, allowing for closed-loop control in certain applications.

## **Wiring:**
1. **Motor Wiring:**
   - Connect the motor windings to the respective outputs on the TMC2209.
   - Windings A (A+, A-) and B (B+, B-) are connected to **OA1**, **OA2**, **OB1**, **OB2** pins.

2. **Encoder Wiring:**
   - **SDA** (I2C Data) to **D4**
   - **SCL** (I2C Clock) to **D5**

3. **Power and bus:**
   - JST-XH 4: 1 GND, 2 +12 V, 3 CAN_H, 4 CAN_L.

## XIAO pin connections

Same as the [FRAME electronics](../frame/README.md) stepper-backpack pinout:

| XIAO pin | Function |
|---|---|
| D0 | Endstop |
| D1 | CAN RX (SCL on the old I2C bus) |
| D2 | CAN TX (SDA on the old I2C bus) |
| D3 | TMC2209 DIAG |
| D4 / D5 | I2C SDA / SCL to encoder |
| D6 / D7 | UART send to / receive from TMC2209 |
| D8 | DIR |
| D9 | STEP |
| D10 | EN |

## **Connections to Stepper Motor Controller (TMC2209):**
- **DIR**: Controls the direction of the stepper motor.
- **STEP**: Steps the motor in the specified direction.
- **UART_PICO**: UART communication to the TMC2209 (TX from Xiao).
- **UART_POCI**: UART communication from the TMC2209 (RX to Xiao).
- **I2C SDA / SCL**: Communication with an external encoder (such as the AS5600 rotational encoder).

## Code Example

Here’s a basic ESP32S3 code to control the TMC2209 stepper motor driver and AS5600 encoder (since AS5300 is typically a typo for AS5600, which is more common) in a feedback loop for 360° rotation in both directions. The code sets up the motor driver and encoder, reads the encoder's position, and runs the motor for a full revolution in either direction based on feedback from the encoder.

## Required Libraries:
- **TMCStepper** for communicating with the TMC2209 driver.
- **Wire** for I2C communication with the AS5600 encoder.

## Wiring:
- **EN** -> D10
- **DIR** (Direction) -> D8
- **STEP** (Step Pulse) -> D9
- **I2C SDA** -> D4
- **I2C SCL** -> D5
- **UART TX** -> D6
- **UART RX** -> D7

## In Action:



## Code:

Standalone test sketch (single-character commands `0`/`1` on the USB serial), not the UC2 firmware. The UC2 firmware for this board is the env `UC2_canopen_slave_motor`.

```cpp
#include <FastAccelStepper.h> // Include the FastAccelStepper library
#include <TMCStepper.h>
#include <Wire.h>

// TMC2209 Settings
#define STALL_VALUE 100     // StallGuard sensitivity [0..255]
#define EN_PIN D10          // Enable pin for motor driver
#define DIR_PIN D8          // Direction pin
#define STEP_PIN D9         // Step pin
#define SW_RX D7            // UART RX pin for TMC2209
#define SW_TX D6            // UART TX pin for TMC2209
#define SERIAL_PORT Serial1 // UART Serial port for TMC2209
#define DRIVER_ADDRESS 0b00 // TMC2209 driver address
#define R_SENSE 0.11f       // Current sense resistor for TMC2209
#define MOT_DIAG D3

// AS5311 I2C Settings
#define SDA_PIN D4       // I2C SDA
#define SCL_PIN D5       // I2C SCL
#define AS5311_ADDR 0x36 // I2C address for AS5311

// Encoder settings
#define MAX_ENCODER_VALUE                                                      \
  16384 // AS5311 is a 14-bit encoder (2^14 = 16384 steps per revolution)

// FastAccelStepper setup
FastAccelStepperEngine engine =
    FastAccelStepperEngine();     // FastAccelStepper engine instance
FastAccelStepper *stepper = NULL; // FastAccelStepper instance

// TMC2209 instance
TMC2209Stepper driver(&SERIAL_PORT, R_SENSE, DRIVER_ADDRESS);

// Function to read AS5311 encoder value over I2C
int readEncoder() {
  Wire.beginTransmission(AS5311_ADDR);
  Wire.write(0x0C); // Register for reading high byte of encoder position
  Wire.endTransmission();
  Wire.requestFrom(AS5311_ADDR, 2);
  int high_byte = Wire.read();
  int low_byte = Wire.read();
  int position = (high_byte << 8) | low_byte;
  return position;
}

void setup() {
  Serial.begin(115200); // Init serial port and set baudrate
  while (!Serial)
    ; // Wait for serial port to connect
  Serial.println("\nStart...");

  // Start Serial communication for TMC2209
  SERIAL_PORT.begin(115200);

  // Pin setup for motor control
  pinMode(EN_PIN, OUTPUT);
  digitalWrite(EN_PIN, LOW); // Enable motor driver (LOW to enable)

  // Setup TMC2209 driver
  driver.begin();             // Initiate TMC2209
  driver.toff(4);             // Enable driver with off time
  driver.blank_time(24);      // Set blank time
  driver.rms_current(400);    // Set motor current to 400mA
  driver.microsteps(16);      // Set microstepping to 16
  driver.TCOOLTHRS(0xFFFFF);  // Set threshold for switching to StealthChop
  driver.semin(5);            // Enable StallGuard with minimum threshold
  driver.semax(2);            // Set maximum StallGuard threshold
  driver.sedn(0b01);          // Set StallGuard deceleration
  driver.SGTHRS(STALL_VALUE); // Set StallGuard sensitivity

  // Setup I2C for AS5311 encoder
  Wire.begin(SDA_PIN, SCL_PIN); // Initialize I2C with specified pins

  // FastAccelStepper setup
  engine.init(); // Initialize the FastAccelStepper engine
  stepper =
      engine.stepperConnectToPin(STEP_PIN); // Connect stepper to the STEP_PIN
  if (stepper) {
    stepper->setDirectionPin(DIR_PIN); // Set the direction pin
    stepper->setEnablePin(EN_PIN);     // Set the enable pin
    stepper->enableOutputs();          // Enable motor outputs
    stepper->setAutoEnable(true);      // Automatically enable motor when moving
    stepper->setSpeedInHz(10000);      // Set initial speed (steps per second)
    stepper->setAcceleration(10000);   // Set acceleration in steps/second^2
  }
}

void loop() {
  static uint32_t last_time = 0;
  uint32_t ms = millis();

  // Read encoder position and use it in feedback loop
  int encoderValue = readEncoder();

  // Control motor movement based on encoder feedback
  /*
  if (encoderValue < MAX_ENCODER_VALUE / 2) {
    stepper->moveTo(1000);  // Move forward by 1000 steps
  } else if (encoderValue >= MAX_ENCODER_VALUE / 2 && encoderValue <
  MAX_ENCODER_VALUE) { stepper->moveTo(-1000); // Move backward by 1000 steps
  }*/

  // Adjust speed via serial input
  while (Serial.available() > 0) {
    int8_t read_byte = Serial.read();
    if (read_byte == '0') {
      Serial.println("Stop");
      stepper->forceStop(); // Stop the motor
    } else if (read_byte == '1') {
      Serial.println("Start");
      stepper->move(10000); // Move forward by 1000 steps
    }
    /*
    else if (read_byte == '+') {
      stepper->setSpeedInHz(stepper->getSpeedInHz() + 100); // Speed up motor
    }
    else if (read_byte == '-') {
      stepper->setSpeedInHz(stepper->getSpeedInHz() - 100); // Slow down motor
    }*/
  }

  // Print StallGuard results and motor current every 100ms
  if ((ms - last_time) > 100) {
    last_time = ms;
    Serial.print("SG Result: ");
    Serial.print(driver.SG_RESULT(), DEC); // Print StallGuard value
    Serial.print(" Current: ");
    Serial.println(driver.cs2rms(driver.cs_actual()),
                   DEC); // Print motor current
    Serial.print("Encoder Value: ");
    Serial.println(encoderValue);
  }
}
```

## Key Components:
1. **Setup TMC2209**: The motor driver is initialized using UART communication and the current limit is set. StealthChop mode is enabled for quieter operation.
2. **Encoder Setup (AS5600)**: Uses I2C to read the encoder’s current position. The encoder provides feedback with a 12-bit resolution (4096 steps per revolution).
3. **MoveStepper Function**: Moves the motor in a given direction (based on step count). The direction and steps are controlled using the DIR and STEP pins.
4. **Feedback Loop**: The motor moves based on encoder feedback. If the encoder position is less than 180° (half of 4096 steps), the motor moves forward; otherwise, it moves backward to maintain a 360° operation.

## Revision: CAN BUS

The CAN revision (Rev C, 2025-01) has a dedicated CAN transceiver on D1/D2 and power safety features. Firmware, node IDs and termination: see the table under Overview; pinout: see [XIAO pin connections](#xiao-pin-connections).

## Attention:

Rev C can be converted between 12V+CAN and 5V+I2C with the marked jumpers and resistors. JP101 joins the 12 V and 5 V nets: never connect 12 V while it is closed. Details: [FRAME electronics](../frame/README.md).



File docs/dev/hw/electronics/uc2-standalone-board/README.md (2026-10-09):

---
sidebar_position: 10
---

# UC2 Standalone Board

The UC2 Standalone Board is the central control unit for automated UC2 microscopy systems. Based on the ESP32 microcontroller, this board provides comprehensive control over motors, LEDs, cameras, and external devices.

## Key Features

- **4 Motor Controllers:** Drive up to 4 stepper motors simultaneously (compatible with A4988 bipolar stepper drivers)
- **High-Power LED Control:** 3 Darlington transistors (BD809) for driving multiple high-power LEDs
- **Wireless Connectivity:** WiFi, Bluetooth, and USB Serial communication via ESP32
- **PS3/PS4 Controller Support:** Intuitive wireless control of your microscope
- **NeoPixel Support:** Control Adafruit's WS2812B RGB LED arrays
- **Camera Triggering:** Synchronize image acquisition with scanning
- **Galvo Scanning:** Generate scanning patterns for galvanometer mirrors
- **I2C Interface:** Control and read external devices

## Board Versions

Multiple versions of the board are available with different features and layouts:
- **UC2 Standalone V2:** Original design with 4 motor drivers
- **UC2 Standalone V3 (Beta):** Enhanced version with improved layout
- **UC2 Standalone V4:** Latest version with additional features

## Tutorials in this Section

- [Board Schematics V2](./schematics-v2.md) - Detailed layout and wiring for version 2
- [Board Schematics V3](./schematics-v3.md) - Beta version documentation
- [Board Schematics V4](./schematics-v4.md) - Latest board version guide

## Connectivity Options

- **WiFi:** Remote control and monitoring
- **Bluetooth:** Wireless PS4 controller connection
- **USB Serial:** Direct computer connection (most commonly used)

## Interfaces

| | `UC2_3` / `UC2_4` | `UC2_canopen_standalone_v4_release` |
|---|---|---|
| Board | v3 / v4 | v4 |
| Role | standalone, no CAN | CAN master, node 1 (hybrid) |
| Serial | USB, 115200 baud, serial JSON | USB, 115200 baud, serial JSON |
| CAN | – | 500 kbit/s, TX GPIO32 / RX GPIO33 |
| Local | motors A/X/Y/Z, lasers, LED | motors A/X/Y/Z, lasers 1–3, LED |
| Via CAN | – | illumination board (node 30: LED + laser id 4), galvo (node 40) |

- The USB-serial chip depends on the ESP32 DevKit: CP2102 or CH340. Install the matching driver if no port appears.
- In the hybrid build, extra CAN motors (stepper id ≥ 4) are not routed by the current firmware. For CAN axes use the [HAT+](../hat-plus/README.md).
- Protocol and clients: [Serial & CANopen interface](../../../sw/interface/index.md). First test: [First serial command](../../../sw/interface/tutorials/first-serial-command.md).

## Connected Components

- Stepper motors for XYZ stages
- LED arrays and matrices
- Cameras with trigger capability
- Galvanometer mirrors
- External sensors via I2C
- High-power laser diodes

## Important Notes

⚠️ **Power Safety:**
- Always disconnect 12V power before changing cables
- Do not power motor drivers without motors attached
- Ensure proper electric load to prevent driver damage

⚠️ **LED Array Polarity:**
- LED polarity matters! Connect carefully
- JST connector: RED (5V), Black (Data), Black (GND)
- WS2812B LEDs can survive reverse polarity but avoid it

## Technical Specifications

- **Microcontroller:** ESP32 Dev Kit
- **Motor Drivers:** 4x A4988 or compatible
- **LED Drivers:** 3x BD809 Darlington transistors
- **Input Voltage:** 12V DC
- **Connectors:** 2.54mm spaced male pins, JST compatible
- **Communication:** WiFi, Bluetooth, USB Serial, I2C

Perfect for building automated microscopy systems with comprehensive electronic control!

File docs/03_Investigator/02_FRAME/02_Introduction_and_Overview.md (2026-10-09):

# Introduction and Overview

## What is the FRAME Microscope?

The **FRAME** (Fast Rigid Automated Microscope Engine) represents a new approach to microscopy: an open, modular, automated, and flexibly adaptable microscope system. Based on UC2's (You.See.Too.) modular optics kit, the FRAME system lowers barriers to access complex optical and microscopy technology.

## System Philosophy

### Modular Design Principles

The FRAME system is built on complete modularization of all components regarding mechanics, electronics, and software:

- **Interchangeable Modules**: Cube modules can be freely exchanged to switch between brightfield, fluorescence, or interference microscopy
- **Flexible Mechanics**: Allows both, classical objective setups and free arrangements for special geometries
- **Smart Electronics**: Each cube can optionally have its own control unit for motors, galvo mirrors, or LEDs. All components share the same CAN BUS via 12V supply voltage.
- **Open Interface**: System control via user-friendly graphical interface or programming interface (Python, REST, CAN BUS, USB)

### Key Innovation Areas

1. **Accessibility**: Open-source hardware and software increase transparency, longevity, and interoperability
2. **Automation**: Open system allows straightforward automation with built-in APIs for software control, camera integration, and laboratory automation
3. **Modularity**: Instead of purchasing a completely new microscope, users can exchange or expand individual modules
4. **Cost Efficiency**: Compared to proprietary complete systems, costs are reduced by 50-90% depending on configuration

## System Overview

### Mechanical Foundation

- **Robust Aluminum Frame**: Provides stable foundation for precise measurements
- **Precision XYZ System**: High-accuracy positioning and focusing mechanisms
- **Removable Optics Unit**: Modular design allows easy reconfiguration
- **Slide-In System**: Standardized 50mm cubes with quick-exchange capability
- **Linear Objective Revolver**: Switch between two different magnifications/resolutions

### Electronic Architecture

- **CAN-BUS System**: Smart networking of all functional units
- **Modular Controllers**: ESP32 and Raspberry Pi-based control systems
- **Remote Operation**: Web-based interface with cloud connectivity
- **IoT Integration**: Network connectivity for remote monitoring and control

### Software Ecosystem

The FRAME system integrates with several software platforms:

- **ImSwitch**: Advanced microscopy control software (http://github.com/openuc2/imswitch)
- **UC2-REST**: Python client (`pip install UC2-REST`, `import uc2rest`) for the ESP32's JSON-over-USB-serial interface (https://github.com/openUC2/UC2-REST, [reference](../../dev/sw/interface/reference/python-uc2rest.md))
- **UC2-ESP**: Firmware for microcontroller-based modules (https://github.com/youseetoo/uc2-esp32); the modules talk CANopen at 500 kbit/s ([Serial & CANopen interface](../../dev/sw/interface/index.md))
- **Python Libraries**: Extensive programming support for automation (e.g. https://github.com/openUC2/ImSwitchClient)

## Applications and Use Cases

### Research Applications

1. **Digital Pathology**: Automated image acquisition with AI analysis for early cancer detection
2. **Cell Biology/Live Cell Imaging**: Long-term observation of living cell cultures in incubators
3. **Laboratory Automation**: Integration with pipetting robots in diagnostics and drug screening
4. **Advanced Microscopy**: Super-resolution techniques, FLIM, and specialized imaging modes

### Industrial Applications

1. **Quality Control**: Materials inspection and defect analysis
2. **Biotechnology**: Process monitoring and product validation
3. **Education**: Modern imaging technique visualization in teaching and training

### Advantages for Different User Groups

#### Research Institutions
- **Flexibility**: Adapt system to specific research needs
- **Cost Efficiency**: Lower initial investment and operational costs
- **Scalability**: Add capabilities as research evolves
- **Community Support**: Active user community and continuous development

#### Biotech Startups
- **Low Entry Barrier**: Affordable access to high-performance microscopy
- **Rapid Prototyping**: Quick iteration on experimental setups
- **Modular Investment**: Build system incrementally as funding allows
- **Open Standards**: Avoid vendor lock-in

#### Educational Institutions
- **Teaching Tool**: Demonstrate modern imaging techniques
- **Student Projects**: Hands-on experience with modular systems
- **Budget Friendly**: Accessible pricing for educational budgets
- **Future Skills**: Prepare students for open-source technologies

## Sustainability and Environmental Impact

### Resource Conservation

The modular approach contributes to sustainability on multiple levels:

1. **Repair & Maintenance**: Instead of disposing of complete systems, only individual modules are replaced or adapted
2. **Upgrading**: When components become outdated or new functions are needed, individual modules can be upgraded rather than replacing the entire system
3. **Local Production**: Many mechanical components are produced locally via 3D printing using renewable materials

### Open Source Benefits

- **Global Accessibility**: Electronic platforms can be replicated worldwide, including in resource-limited regions
- **Knowledge Sharing**: Open documentation promotes global access to high-end technology
- **Community Development**: Active community ensures continuous improvement and support
- **Local Repairs**: Using 3D printing and digital fabrication, broken parts can be repaired on site

## System Configurations

### Base Configuration

The basic FRAME system includes:
- Aluminum frame with XYZ positioning system
- Basic cube modules for brightfield microscopy
- Camera interface and basic illumination
- Control electronics and software

### Advanced Configurations

Extended systems can include:
- Multiple illumination modes (fluorescence, polarization, DIC)
- Automated sample handling
- Multi-camera setups
- Environmental control (temperature, CO₂)
- Integration with laboratory automation systems

## Getting Started

Before proceeding with installation and operation, ensure you have:

1. **Read all safety information** in Section 1
2. **Verified system requirements** detailed in Section 3
3. **Prepared installation space** according to environmental specifications
4. **Organized necessary tools** and accessories for assembly

The following sections will guide you through:
- Technical specifications and requirements
- Step-by-step installation procedures
- Comprehensive operation instructions
- Maintenance and troubleshooting guidance

### Results from the Fluorescence Channels 





*Continue to [Technical Specifications](./03_Technical_Specifications.md) for detailed system requirements and specifications.*

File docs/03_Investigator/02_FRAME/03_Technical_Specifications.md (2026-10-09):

# Technical Specifications

## System Specifications

### System Overview





### Overall System Dimensions (including illumination arm)

| Parameter |  Motorized Version |
|---|---|
| Width | 310 mm  |
| Depth | 410 mm  |
| Height | 400 mm  |
| Weight | 25 kg |

### Mechanical Specifications

#### Frame Construction
- **Material**: Anodized aluminum profiles and plates
- **Vibration Damping**: Integrated damping system (bumper feed)
- **Stage**: Integrated XYZ Stage in one mechanical design
- **Objective Revolver**: 2 Slots for multiple magnifications/resolutions 

### Optical Specifications

#### Objectives Compatibility
- **Thread**: Standard RMS (20.32 mm × 36 TPI) and M25 × 0.75; customizable
- **Magnification Range**: 2× to 100×
- **Numerical Aperture**: Up to 1.4 (oil immersion)
- **Working Distance**: 0.1 mm to 30 mm depending on objective
- **Correction**: Infinity-corrected optics (160 mm and 200 mm tube length)
- **Customization**: Bring your own microscope objective and design the adapter: XXXXX

#### Tube Lens System
- **Focal Length**: 100 mm (standard, customizable)
- **Resolution**: Diffraction limited performance
- **Field Number**: XXX

#### Condenser System
- **Type**: Koehler Illumination, LED Array using Neopixels
- **Numerical Aperture**: 0.3 - 0.5 (LED array/Darkfield)
- **Aperture Control**: Digitally using LED Ring addressing

### Illumination System

#### Transmitted Light
- **LED Illumination**:
  - White LED: 5000K, CRI >90
  - Power: 1W maximum
  - Intensity Control: 0-100% continuous via PWM and current control
  - Lifetime: >5,000 hours

#### Incident Light
- **LED Ring Light**: Adjustable segments for directional lighting
- **Fluorescence**: Modular Laser system with multiple wavelengths
  - UV: 405nm
  - Blue: 488nm
  - Green: 530nm
  - Red: 635nm

### Camera and Detection System

#### Camera Interface
- **Mount Type**: C-mount
- **Sensor Compatibility**: CMOS
- **Available Cameras:** HIK IMX179, IMX275
- **Connection**: USB 3.0
- **Trigger**: Hardware and software trigger support

#### Recommended Camera Specifications
- **Resolution**: 1920 × 1200 to 5472 × 3648 pixels
- **Pixel Size**: 2.4 μm to 6.5 μm
- **Frame Rate**: Up to 200 fps (depending on resolution)
- **Sensitivity**: >60% quantum efficiency
- **Dynamic Range**: >60 dB

### Electronic System

#### Control Electronics
- **Main Controller**: Raspberry Pi 4 or ESP32-based system
- **Communication**: CAN-BUS, USB, Ethernet, WiFi
- **I/O Interfaces**: GPIO, SPI, I2C, UART
- **Power Supply**: 24V DC, 5A (switching power supply included)

#### Motor Controllers
- **Stepper Motors**: NEMA8 (Z), Nema12 (X,Y,Objective), 200 Steps per Revolution, 1mm per revolution
- **Microstepping**: Up to 256 microsteps per step (TMC2009)
- **Position Feedback**: Magnetic  encoders (for x,y - optional)
- **Homing**: Optical limit switches

#### Sensor Integration
- **Temperature**: via I2C
- **Humidity**: via I2C
- **Focus Sensor**: optional: Astigmatism Based via CAN Bus (coming soon)

### Software Specifications

The internal Raspberry Pi 5 runs ImSwitch-OS which is a raspberry pi OS Sd card image that runs ImSwitch in a docker container. An external computer is needed to connect to this instance via Wifi. More to that later in the Operaional Manual 

Changing the SD Card can be done from the rear of the electronics box in side the FRAME. You can find the openUC2 OS in the dedicated repository and download it from ZENODO: https://github.com/openUC2/imswitch-os

 



#### Operating System Compatibility

More information about this here:  https://docs.openuc2.com/ XXX
- **Windows**: Windows 10/11 (64-bit)
- **macOS**: macOS 10.15 or later
- **Linux**: Ubuntu 20.04 LTS or later
- **Web Interface**: Modern browsers (Chrome, Firefox, Safari, Edge)

#### Software Requirements

Frontend-only:
- **RAM**: 8 GB minimum, 16 GB recommended
- **Storage**: 1 GB free space for software, additional space for images
- **Graphics**: OpenGL 3.0 compatible graphics card
- **Network**: Ethernet or WiFi for remote control

### Environmental Requirements

#### Operating Conditions
- **Temperature**: 15°C to 35°C
- **Humidity**: 30% to 80% relative humidity, non-condensing
- **Atmospheric Pressure**: 86 kPa to 106 kPa
- **Altitude**: Up to 2000 m above sea level

#### Storage Conditions
- **Temperature**: -10°C to 60°C (14°F to 140°F)
- **Humidity**: 10% to 95% relative humidity, non-condensing

#### Installation Requirements
- **Vibration**: optical table with vibration damping recommended for best performance
- **Space**: 1 m × 1.5 m minimum work area
- **Power**: 230V AC, 50/60 Hz (or 115V AC with adapter)
- **Ventilation**: Natural convection (no forced ventilation required)

## Component Specifications

### Inner Cube System

#### Cube Modules (Standard 50mm)

#### Mechanical Specifications
- **Dimensions**: 50 × 50 × 50 mm
- **Material**: ABS / injection molded
- **Precision**: ±0.1 mm dimensional accuracy
- **Interface**: Dovetail connection system
- **Mounting**: Threaded inserts M3 and M4 compatible
- **Optical Aperture**: 25mm clear aperture (configurable)

#### Electronic Components
- **Microcontrollers**: ESP32, Arduino-compatible (see https://github.com/youseetoo/uc2-esp32/)
- **Communication**: USB serial (JSON) to the host, CANopen at 500 kbit/s between modules, I2C, SPI
- **Power**: 12V input via the CAN bus cable (JST-XH 4: GND, +12 V, CAN_H, CAN_L), operational voltage 3.3V, 5V
- **Indicators**: LED status lights via Neopixel interface (on board breakout)

#### Optical Specifications
- **Aperture Diameter**: 25mm standard (custom sizes available)
- **Coating**: Anti-reflection coating on optical surfaces
- **Alignment Tolerance**: ±0.02mm lateral, ±0.01mm axial
- **Surface Quality**: 60-40 scratch-dig specification
- **Clear Aperture**: >90% of geometric aperture

### Stage System

#### XYZ Positioning System (Motorized Stage)
- **X-Y Travel Range**: 75 × 50 mm (standard), up to 120 × 90 mm (extended), stepsize: ~300nm
- **Z-Travel Range**: 8 mm, stepsize: ~300nm
- **Resolution**: 0.3 μm (motorized)
- **Accuracy**: ±XXXX μm
- **Repeatability**: ±0.5 μm
- **Speed**: 0.1 μm/s to 10 mm/s
- **Acceleration**: Programmable, up to 100 mm/s²
- **Load Capacity**: 2 kg maximum

### Focus System

#### Motorized Focus
- **Range**: 25 mm
- **Resolution**: 0.05 μm
- **Speed**: 0.1 μm/s to 5 mm/s
- **Repeatability**: ±0.1 μm
- **Autofocus**: Laser-based or image-based (optional)

## Compatibility and Standards

### Microscopy Standards
- **ISO 8038**: Optics and photonics - Microscopes
- **DIN 58887**: Microscopes - Objectives

### Communication Standards
- **CAN ISO-TP**: Controller Area Network protocol
- **USB 3.0**: Universal Serial Bus specification
- **Ethernet**: IEEE 802.3 standard
- **WiFi**: IEEE 802.11ac/ax standards

### Safety Standards
- **IEC 61010-1**: Safety requirements for electrical equipment
- **IEC 62471**: Photobiological safety of lamps and lamp systems
- **EN 55011**: Electromagnetic compatibility

## Performance Specifications

*Continue to [Installation and Setup](./04_Installation_and_Setup.md) for detailed installation procedures.*

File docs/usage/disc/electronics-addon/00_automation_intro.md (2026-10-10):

---
sidebar_label: Tutorial
---

# openUC2 Discovery Electronics Kit - Extended Tutorial

## Introduction

The openUC2 Discovery Electronics Kit empowers users to explore advanced microscopy techniques by combining geometric optics and automation. By utilizing affordable, modular components, this kit allows you to build a fully functioning digital microscope with smart features. It’s an ideal learning tool for educators, students, and hobbyists interested in microscopy, optics, and electronics.


*Electronics components to have a lot of fun with open-source fully automated microscopy*

This tutorial will guide you through building and operating a motorized microscope. By the end of this experiment, you’ll understand how to control a motorized Z-stage for precise focusing, use an LED array for illumination, and experiment with digital contrast methods.

### Applications
This kit is perfect for classrooms or workshops where participants learn how to build and program optical systems. With the added automation, it’s also useful for research projects needing consistent imaging over time or where manual focus and lighting adjustments are too cumbersome. This could include biology labs, maker spaces, or environments that foster innovation in digital imaging.

---
## Components Included in the Kit:

### In Cubes:
2. **Motorized Z-Stage** (NEMA 11 stepper motor)
3. **openUC2 LED Array** (3 concentric circles with NeoPixels)

### Not in Cubes:
1. **Objective Lens** (RMS compatible, 10x finite)
2. **openUC2 Electronic Board** (ESP32-based control unit)
4. **Micro USB Cable** (for connecting ESP32)
4. **USB-C Cable** (for connecting LED Array)
5. **Controller** (PlayStation-style)
6. **12V Power Supply** (to power motors and lights)
4. **Baseplates** (8x for modular setup)

---

## Experiment #1: Testing the USB Serial Interface via the Web

In this first experiment, we’ll walk through how to control the motorized Z-stage and LED array using the web-based serial interface.

### Step 1: Hardware Setup for Testing and controlling the Z-focus Motor
**⚠️ Caution!**
If you need to change any of the cables or their position, always unplug
 the 12V power cable before doing so. Otherwise, the electronic
components might get damaged!

**⚠️**
These instructions based on the Pin-layout of the **ESO32-DEV-based UC2 standalone board V3 (beta)**)
find the Pin-layout for the **ESO32-DEV-based UC2 standalone board V4** [here](https://docs.openuc2.com/docs/Electronics/UC2StandaloneBoard/uc2e2v4)

- connect the LED-Matrix to the Mainboard at `LED1`
- Connect the Z-stage to the position `Z-Motor` on the main board. Ensure there's a motor driver.
- Plug in the micro-USB at your ESP32 and connect to your PC.
- Plug in the 12V power cable.

### Step 2: Flashing the ESP32 Firmware
1. Before proceeding, ensure your ESP32 board has the latest firmware. You can download and flash the firmware via the official [openUC2 website](https://youseetoo.github.io/), selecting the your version, then then click on the connect button.

<p align="center">
<em>Flashing process shown for the ESP32-DEV-based UC2 standalone board V3 (beta).</em>
</p>



The source-code can be found [here](https://github.com/youseetoo/uc2-esp32)

2. Connect the ESP32 to your computer using the micro-USB cable.



3. In your Chrome browser and click on "Connect." A dialog will prompt you to select the COM port for your ESP32. Once connected, you can install the latest firmware by simply clicking the "Install" button. If nothing shows up, you can install the drivers from the following propmpt that results when you hit anywhere on the screen:



4. Wait until the firmware has been flashed successfully.

### Step 3: Connecting and Testing the Web Interface
 (valid since March 2025)
1. After flashing the firmware, go to the testing section on the same website. You’ll find buttons to control the motor and LEDs (This can be tested with the hardware connected or with only the ESP32 connected via USB)



2. Connect to your ESP32 board using the "Connect" button again, ensuring the correct COM port is selected.



3. Once connected, test the system by sending a simple command:

```json
{"task":"/motor_act","motor":{"steppers":[{"stepperid":3,"position":-1000,"speed":1000,"isabs":0}]}}
```

This command will move the Z-axis motor by -1000 steps (1 full rotation) at a speed of 1000 steps per second. Each step corresponds to a movement of 300nm when using microstepping. You’ll see the motor rotate, adjusting the focus.

> **Note:** Ensure the command string has no line breaks.

###Step 4: testing in the Web Interface
(valid since March 2025)
After completing the test, go back to the first tab to control the other components via buttons:
- `Motor Z(+)` and `Motor Z(-)` control the Z-stage.
- `LED (on)` and `LED (off)` control the LED-matrix panel, as well as the other buttons in this section to turn on single LEDs or a ring pattern.



**[VIDEO:] Connect Motor:**

<div style={{position: 'relative', paddingBottom: '56.25%', height: 0, overflow: 'hidden'}}>
  <iframe
    style={{position: 'absolute', top: 0, left: 0, width: '100%', height: '100%'}}
    src="https://www.youtube.com/embed/TsWAeWl2T10?si=Z3GzSg2Xhjy6u3jf"
    title="YouTube video player"
    frameBorder="0"
    allow="accelerometer; autoplay; clipboard-write; encrypted-media; gyroscope; picture-in-picture"
    allowFullScreen
  />
</div>

### Step 4: Controlling the LED Array (obsolete since March 2025)

1. Use the web interface to turn the LEDs on and off or control brightness.
2. Try adjusting the LED patterns (e.g., lighting only certain rings) using the available commands. The first command below fills all LEDs green, the second one switches on a single LED. All LED actions (`fill`, `off`, `single`, `halves`, `rings`, `circles`) are listed in the [serial command reference](../../../dev/sw/interface/reference/serial-commands.md#ledarr_act).

```json
{"task":"/ledarr_act","led":{"action":"fill","r":0,"g":50,"b":0}}
{"task":"/ledarr_act","led":{"action":"single","ledIndex":0,"r":0,"g":50,"b":0}}
```

text

Experiment with other colors by changing the RGB values.

**[VIDEO:] Connect LED:**

<div style={{position: 'relative', paddingBottom: '56.25%', height: 0, overflow: 'hidden'}}>
  <iframe
    style={{position: 'absolute', top: 0, left: 0, width: '100%', height: '100%'}}
    src="https://www.youtube.com/embed/l8rRLvF6X6g?si=w-AXCYUHzXj2p1m5"
    title="YouTube video player"
    frameBorder="0"
    allow="accelerometer; autoplay; clipboard-write; encrypted-media; gyroscope; picture-in-picture"
    allowFullScreen
  />
</div>

This first exercise gives you a solid introduction to controlling basic components of the openUC2 system. In future tutorials, we will explore more advanced techniques, such as automated focus stacking and digital phase-contrast imaging -> for this you can have a look [here](https://docs.openuc2.com/docs/Toolboxes/InfinityBox/DPCmicroscopy)

Feel free to experiment further with different motor and LED settings to familiarize yourself with the control interface. If you have question reach out to us in our forum: openuc2.discourse.group.

## Experiment #2: Building a Microscope and Controlling it with the PS4 Controller

In this experiment, you will build a digital microscope using the components from the openUC2 Discovery Kit and learn how to control the microscope’s motorized stage and LED array using a PS4 controller. This setup allows for intuitive control, perfect for navigating a sample on the XY stage or adjusting focus.

### Step 1: Pairing the PS4 Controller

The UC2-ESP firmware is designed to support various input devices, including the PS4 controller, making it easier to interact with the microscope. You’ve already worked with USB Serial commands, but using the PS4 controller will give you a more flexible, hands-on approach.

#### How to Pair the PS4 Controller:

For more detailed instructions on pairing, refer to the [UC2 PS4 Controller Pairing Guide](https://docs.openuc2.com/docs/Electronics/PS4-Controller/PS4-Controller)(valid since June 2025). But briefly:

1. First, put your PS4 controller into pairing mode by holding down the **Share** button and the **PS button** simultaneously until the light bar starts blinking.
2. Open the serial prompt in your browser (connected to the ESP32 board) or use the web interface.
3. Enter the command:

```json
{"task":"/bt_scan"}
```
This will initiate the Bluetooth scan on the ESP32, which will detect and pair with the controller. Alternatively, you can use the **"Pair Controller"** button in the web interface.

4. Once paired, you should be able to control the motorized stage using the analog sticks on the controller and switch the LED array on/off using the buttons.

### Step 2: Building the Microscope

Next, you will build a motorized digital microscope using the components provided in the kit. This setup will be similar to the **smartphone microscope**, which can be found in detail [here](https://docs.openuc2.com/docs/Toolboxes/CoreBox/ENGLISH/coreMicroscope#tutorial-smartphone-microscope), but with the added feature of a motorized Z-stage for fine-tuning the focus and the monocrhome USB-3 caemra

#### Components Needed (in addition to the Smartphone micrsocope):
- **Objective Lens** (RMS 10x or 4x)
- **Motorized Z-Stage** (NEMA 11 stepper motor)
- **LED Array** (for illumination)
- **ESP32 Electronics Board** (with 12V power supply)
- **PS4 Controller**

#### Step-by-Step Assembly:
1. **Mount the Objective Lens**: Attach the RMS-compatible objective to the lens holder on the Z-stage.
2. **Assemble the Z-Stage**: Attach the motorized Z-stage to the base plate and secure the camera above it using the provided baseplates and cubes.
3. **Connect the Electronics**: Plug in the ESP32 board, motorized stage, and LED array. Ensure the 12V power supply is connected to provide power to the motors and LEDs.

For detailed assembly steps, refer to the **smartphone microscope** tutorial, which provides an in-depth guide to building the optical system.

Now that the microscope is built and the PS4 controller is paired, you can control the motorized Z-stage and LED array:

- **Move the Z-stage**: Use the **left analog stick** to move the stage up and down (adjust focus).
- **Control the LEDs**: Use the **controller buttons** to turn the LED array on/off and cycle through different illumination patterns.

This setup allows you to navigate through your sample and adjust focus without touching the hardware, which is particularly useful when working with sensitive samples or in teaching environments where ease of use is essential.

## Experiment #3: Controlling the UC2 Electronics using ImSwitch

In this experiment, you'll combine everything you've learned so far by controlling the UC2 system through ImSwitch, a powerful software interface designed for modular microscopy control. This tutorial provides a basic introduction to setting up ImSwitch, configuring your microscope components, and automating functions such as stage movement and LED control.

---

### Step 1: Installing ImSwitch

There are two ways to install ImSwitch, depending on your system preferences.

#### Method 1: Install ImSwitch via Python Package (with Napari support)

A more detailed explantion can be found here: https://openuc2.discourse.group/t/imswitch-installation-on-mac-and-windows/37

1. **Set up your Python environment** (using Conda or Mamba):
   ```bash
   mamba create -n imswitchhackathon python=3.9 -y
   mamba activate imswitchhackathon
   ```

2. **Install ImSwitch**:
   ```bash
   pip install https://github.com/openUC2/ImSwitch/archive/refs/heads/master.zip # this installs the lastest master
   # do the same if you want to update the system
   # alternative:
   git clone https://github.com/openUC2/ImSwitch/
   cd ImSwitch
   pip install -e .
   ```

3. **Optional**: Install the required dependencies for QT and Napari:
   ```bash
   pip install pyqtgraph qdarkstyle
   ```

This setup will allow you to run ImSwitch with full functionality, including graphical user interface (GUI) support for Napari.

#### Method 2: Running ImSwitch using Docker

For a simpler, platform-agnostic solution, you can run ImSwitch using Docker:

1. **Pull the Docker container**:
   ```bash
   sudo docker pull ghcr.io/openuc2/imswitch-noqt-x64:latest
   ```

2. **Run the Docker container**:
   ```bash
   sudo docker run -it --rm -p 8001:8001 -p 2222:22 \
   -e HEADLESS=1 \
   -e HTTP_PORT=8001 \
   -e CONFIG_FILE=example_uc2_hik_flowstop.json \
   -e CONFIG_PATH=/config \
   -v ~/Downloads:/config \
   --privileged ghcr.io/openuc2/imswitch-noqt-x64:latest
   ```

Once you have ImSwitch installed and running, you can access the web interface at `localhost:8001` to control the system.

For detailed instructions on Docker installation, visit the [ImSwitch Docker Guide](https://docs.openuc2.com/docs/ImSwitch/Advanced/ImSwitchDocker).

---

### Step 2: Using the ImSwitch Config File

Now that ImSwitch is installed, you need to configure it for your specific setup. Here is an example configuration file (`uc2_hik_histo.json`) for controlling the UC2 system:

```json
{
  "positioners": {
    "ESP32Stage": {
      "managerName": "ESP32StageManager",
      "managerProperties": {
        "rs232device": "ESP32",
        "stepsizeX": -0.3125,
        "stepsizeY": -0.3125,
        "stepsizeZ": 0.3125,
        "homeSpeedX": 15000,
        "homeSpeedY": 15000,
        "homeSpeedZ": 15000
      },
      "axes": ["X", "Y", "Z"],
      "forScanning": true
    }
  },
  "rs232devices": {
    "ESP32": {
      "managerName": "ESP32Manager",
      "managerProperties": {
        "host_": "192.168.43.129",
        "serialport": "COM3"
      }
    }
  },
  "lasers": {
    "LED": {
      "managerName": "ESP32LEDLaserManager",
      "managerProperties": {
        "rs232device": "ESP32",
        "channel_index": 1
      },
      "wavelength": 635
    }
  },
  "detectors": {
    "WidefieldCamera": {
      "managerName": "HikCamManager",
      "managerProperties": {
        "isRGB": 1,
        "hikcam": {
          "exposure": 0,
          "gain": 0,
          "blacklevel": 100,
          "image_width": 1000,
          "image_height": 1000
        }
      },
      "forAcquisition": true
    }
  },
  "autofocus": {
    "camera": "WidefieldCamera",
    "positioner": "ESP32Stage",
    "updateFreq": 10,
    "frameCropx": 780,
    "frameCropy": 400
  }
}
```

This file configures the ESP32 stage, LED control, and the camera for widefield imaging. Ensure the `host_` and `serialport` match your system setup.

---

### Step 3: Running the Microscope with ImSwitch

1. **Launch ImSwitch**:
   ```bash
   python -m imswitch
   ```

2. **Select the Configuration**:
   Upon launch, choose **"Virtual Microscope"** or load your custom configuration file, such as `uc2_hik_histo.json`.

3. **Control the System**:
   Use the ImSwitch GUI to move the motorized stage, control the LED array, and capture images. The interface allows you to automate tasks such as focus stacking and digital phase-contrast imaging.

### Video Tutorial

For a visual guide on how to set up ImSwitch and control the UC2 system, watch the following video:

<div style={{position: 'relative', paddingBottom: '56.25%', height: 0, overflow: 'hidden'}}>
  <iframe
    style={{position: 'absolute', top: 0, left: 0, width: '100%', height: '100%'}}
    src="https://www.youtube.com/embed/Iw_Bg9aYe1U?si=VQgLP854Hg29dwxW"
    title="YouTube video player"
    frameBorder="0"
    allow="accelerometer; autoplay; clipboard-write; encrypted-media; gyroscope; picture-in-picture"
    allowFullScreen
  />
</div>

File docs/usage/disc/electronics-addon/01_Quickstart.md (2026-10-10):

# Quickstart on controlling electronics
in this QUickstart Guide,  we’ll walk through how to control the motorized Z-stage and LED array using the web-based serial interface, as well as an PS4 controller.

### Step 1: Flashing the ESP32 Firmware
1. Before proceeding, ensure your ESP32 board has the latest firmware. You can download and flash the firmware via the official [openUC2 website](https://youseetoo.github.io/), selecting the appropriate version (currently v3 Standalone).


*Choose the ESP32 v3 board (not BETA or re-work!) and flash it (but only if you need an update)*

The source-code can be found [here](https://github.com/youseetoo/uc2-esp32)

2. Connect the ESP32 to your computer using the micro-USB cable.



3. In your Chrome browser and click on "Connect." A dialog will prompt you to select the COM port for your ESP32, which should show as `CP210x` (or `CH340`, depending on the board). Once connected, you can install the latest firmware by simply clicking the "Install" button. If nothing shows up, you can install the drivers from the following propmpt that results when you hit anywhere on the screen:



4. Wait until the firmware has been flashed successfully.

### Step 2: Connecting and Testing the Web Interface
1. After flashing the firmware, go to the testing section on the same website. You’ll find buttons to control the motor and LEDs (This can be tested with the hardware connected or with only the ESP32 connected via USB)



2. Connect to your ESP32 board using the "Connect" button again, ensuring the correct COM port is selected.



3. Once connected, test the system by sending a simple command:

```json
{"task":"/motor_act","motor":{"steppers":[{"stepperid":3,"position":-1000,"speed":1000,"isabs":0}]}}
```

This command will move the Z-axis motor by -1000 steps (1 full rotation) at a speed of 1000 steps per second. Each step corresponds to a movement of 300nm when using microstepping. You’ll see the motor rotate, adjusting the focus.

> **Note:** Ensure the command string has no line breaks.

### Step 3: Hardware Setup for Testing and controlling the Z-focus Motor
1. Plug the ESP32 board into your computer via USB.
2. Connect the 12V power supply to the provided port.
3. Attach the NEMA 11 motor to the Z-motor port on the board.
4. Turn on the system and verify that the motor responds to commands.
5. The motor should move when you enter the command or hit the buttons.



**[VIDEO:] Connect Motor:**

<div style={{position: 'relative', paddingBottom: '56.25%', height: 0, overflow: 'hidden'}}>
  <iframe 
    style={{position: 'absolute', top: 0, left: 0, width: '100%', height: '100%'}}
    src="https://www.youtube.com/embed/TsWAeWl2T10?si=Z3GzSg2Xhjy6u3jf" 
    title="YouTube video player" 
    frameBorder="0" 
    allow="accelerometer; autoplay; clipboard-write; encrypted-media; gyroscope; picture-in-picture" 
    allowFullScreen
  />
</div>

### Step 4: Controlling the LED Array

1. Use the web interface to turn the LEDs on and off or control brightness.
2. Try adjusting the LED patterns (e.g., lighting only certain rings) using the available commands. The first command below fills all LEDs green, the second one switches on a single LED. All LED actions (`fill`, `off`, `single`, `halves`, `rings`, `circles`) are listed in the [serial command reference](../../../dev/sw/interface/reference/serial-commands.md#ledarr_act).

```json
{"task":"/ledarr_act","led":{"action":"fill","r":0,"g":50,"b":0}}
{"task":"/ledarr_act","led":{"action":"single","ledIndex":0,"r":0,"g":50,"b":0}}

```

text

Experiment with other colors by changing the RGB values.

**[VIDEO:] Connect LED:**

<div style={{position: 'relative', paddingBottom: '56.25%', height: 0, overflow: 'hidden'}}>
  <iframe 
    style={{position: 'absolute', top: 0, left: 0, width: '100%', height: '100%'}}
    src="https://www.youtube.com/embed/l8rRLvF6X6g?si=w-AXCYUHzXj2p1m5" 
    title="YouTube video player" 
    frameBorder="0" 
    allow="accelerometer; autoplay; clipboard-write; encrypted-media; gyroscope; picture-in-picture" 
    allowFullScreen
  />
</div>

This first exercise gives you a solid introduction to controlling basic components of the openUC2 system. In future tutorials, we will explore more advanced techniques, such as automated focus stacking and digital phase-contrast imaging -> for this you can have a look [here](https://docs.openuc2.com/docs/Toolboxes/InfinityBox/DPCmicroscopy)

Feel free to experiment further with different motor and LED settings to familiarize yourself with the control interface. If you have question reach out to us in our forum: openuc2.discourse.group.

### Step 5: Pairing the PS4 Controller

The UC2-ESP firmware is designed to support various input devices, including the PS4 controller, making it easier to interact with the microscope. You’ve already worked with USB Serial commands, but using the PS4 controller will give you a more flexible, hands-on approach.

#### How to Pair the PS4 Controller:

For more detailed instructions on pairing, refer to the [UC2 PS4 Controller Pairing Guide](https://docs.openuc2.com/docs/Electronics/PS4-Controller/PS4-Controller). But briefly:

1. First, put your PS4 controller into pairing mode by holding down the **Share** button and the **PS button** simultaneously until the light bar starts blinking.
2. Open the serial prompt in your browser (connected to the ESP32 board) or use the web interface.
3. Enter the command:

```json
{"task":"/bt_scan"}
```
This will initiate the Bluetooth scan on the ESP32, which will detect and pair with the controller. Alternatively, you can use the **"Pair Controller"** button in the web interface.

4. Once paired, you should be able to control the motorized stage using the analog sticks on the controller and switch the LED array on/off using the buttons.

- **Move the Z-stage**: Use the **left analog stick** to move the stage up and down (adjust focus).
- **Control the LEDs**: Use the **controller buttons** to turn the LED array on/off and cycle through different illumination patterns.

This setup allows you to navigate through your sample and adjust focus without touching the hardware, which is particularly useful when working with sensitive samples or in teaching environments where ease of use is essential.

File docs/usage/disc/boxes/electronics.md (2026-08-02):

openUC2 GmbH
Search...
All Products
Discovery | Electronics Add-On
Discovery | Electronics Add-On
Discovery | Electronics Add-On
IMG_6599.webp
IMG_6621-1.webp
IMG_6611.webp
Discovery | Electronics Add-On
openUC2 Electronics Add-On 

 Does not work without CoreBox 

Automate Your Microscope with Ease

The openUC2 Electronics Add-On is a modular and open-source toolkit designed to introduce you to the automation of traditional microscopes. With cutting-edge components like an ESP32 microcontroller, stepper motor drivers, and an advanced LED array, this kit provides everything you need to start exploring automated imaging workflows.

Included Components
Cube Modules

Electronic Z-Stage (NEMA 11 motor, RMS Thread, 25mm travel range, &lt;1µm step size)
LED Array (for advanced illumination techniques)
Additional Accessories

10x Puzzle Baseplates
1x Objective Lens (10x, NA=0.25, finite)
UC2 Electronics (ESP32-based, 2x2 cube, slots for TMC2209 stepper drivers, ports for LEDs, lasers, and other peripherals, compatible with UC2-eSP firmware)
Micro USB Cable and USB-C Cable
PS4-Compatible Controller (wireless control)
12V Power Supply
Features and Applications

ESP32 Microcontroller: Runs the UC2-eSP firmware for seamless integration with Python, JavaScript, and other programming interfaces.
Precision Automation: Achieve sub-micron accuracy with the Z-stage, enabling advanced tasks like autofocus by capturing contrast curves.
Remote Control: Use the PS4 controller for intuitive, wireless operation of the microscope.
LED Array: Test and experiment with digital contrast techniques, such as differential phase contrast (DPC).
Software Integration: Quickly integrate the electronics into the Python-based ImSwitch software for advanced control and imaging.

Explore Advanced Automation Today

Transform your microscope into a fully automated imaging system with the openUC2 Electronics Add-On. Experiment, innovate, and build workflows tailored to your research needs.

Learn More

549.00 € VAT Excluded
1
Only 2 Units left in stock.
Terms and Conditions
Shipping: on stock, within 2 weeks! 

Expand Your Setup
This is an Add-On to be combined your openUC2 CoreBox for extended capabilities. While this set does not include a camera, upgrading to the Infinity Package adds imaging functionalities to complete your automated microscope.

Useful Links
Home
About us
Products
Privacy Conditions
Terms & Conditions 
Contact us
Cancellation policy
Imprint
About us
We are a team of passionate people whose goal is to improve everyone's life through disruptive products. We build great products to solve your business problems.

Our products are designed for small to medium size companies willing to optimize their performance.

Connect with us
hello@openuc2.com
Contact us

Copyright © 2022 - 2026 OpenUC2 GmbH. All Rights reserved.
Cookie Policy

Powered by Odoo - The #1 Open Source eCommerce

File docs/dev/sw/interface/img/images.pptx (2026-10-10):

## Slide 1

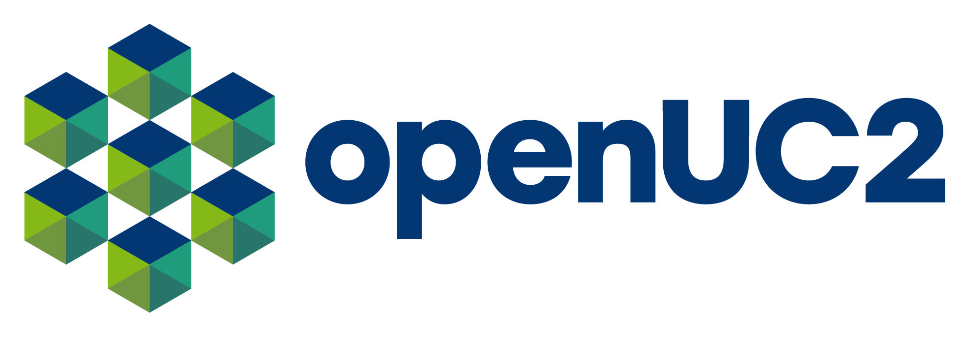
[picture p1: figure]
openUC2 - The optical toolbox

One remote motor move (serial → CANopen → serial)

Host (uc2rest)

ESP32 master

node 1 | DeviceRouter

Motor satellite X

node 11

1 /motor_act | stepperid 1 | position 1000 | speed 20000 | qid 5

3 expedited SDO writes to 0x60B, each acknowledged on 0x58B:

2 RoutingTable: MOTOR 1 → REMOTE, node 11, subAxis 1

(LOCAL would start FastAccelStepper directly)

4 SDO 0x2003:00 = 0x02 (bit n = start slot n, bit n+4 = stop slot n)

0x2000:02 target | 0x2002:02 speed | [0x2006:02 accel]

0x2007:02 is_absolute | 0x200B:02 is_forever

5 ack: {"steppers":[{"stepperid":1,"isDone":0}],"qid":5}

6 TPDO1 0x18B: position i32 | status (bit0 running = 1) | homing u8

on change (≥ 10 ms apart) and every 500 ms

8 {"steppers":[{"stepperid":1,"position":1000,"isDone":1}],"qid":5}

7 TPDO1 0x18B: running = 0 → master sees the stop edge

9 {"qid":5,"state":"done"} (QidRegistry, all axes of qid 5 done)

Feedback for steps 6–7 arrives only from nodes 10–13:

the master's RPDOs listen on fixed COB-IDs 0x18A–0x18D.

With uc2canopen (path B) the Pi sends 3–4 itself and reads 6–7 directly.

Master = HAT+ ESP32 (UC2_canopen_master). stepperid 1 (X) is routed to node 11, OD sub-index stepperid+1 = 2. A local axis skips steps 3–4 and 6–7.

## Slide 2

UC2 control topologies

A | Standalone board v4

Host sends JSON over USB. v4 drives its own axes; CAN carries illumination and galvo.

ImSwitch | uc2rest (Python) | WebSerial | any serial terminal

env UC2_canopen_standalone_v4_release | CANopen master, node 1

DeviceRouter: each device id is routed LOCAL or to a CAN node.

Laser id 4, LED array and galvo → CAN by default.

500 kbit/s | CAN_H solid / CAN_L dashed | 12 V on JST-XH 4

Extra CAN motors (stepperid ≥ 4) are not routed by this

firmware yet. Use the HAT+ topology (B) for CAN axes.

One CANopen master (node 1) per bus. Satellites are CANopen slaves. Node IDs shown are firmware defaults.

B | Raspberry Pi 5 + HAT+ (FRAME)

Two ways onto the same bus: via the ESP32 master (A) or directly via can0 (B).

ImSwitch | uc2rest (path A) | uc2canopen (path B)

Bridges send their own SDOs to the satellites (extra SDO clients on the bus).

Host: PC or Raspberry Pi

USB serial | JSON | 115200 8N1

path A | JSON | 921600

Raspberry Pi 5

path B | SPI0 CE0

Standalone board v4 (ESP32)

UART GPIO14/15 or USB-C

HAT+ v2 | J102 JST-XH 4 | 120 Ω jumper JP801

ESP32-WROOM-32E

env UC2_canopen_master

CANopen master, node 1

bus power GPIO4 | E-stop GPIO34

TWAI TX17 / RX18

MCP2515 + SN65HVD230

Linux SocketCAN can0
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

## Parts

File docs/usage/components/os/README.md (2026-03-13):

# openUC2 OS

openUC2 OS is the operating system for openUC2 machines.
It is a customization layer over [Raspberry Pi OS](https://www.raspberrypi.com/software/operating-systems/), with a version-controlled OS configuration and update system.

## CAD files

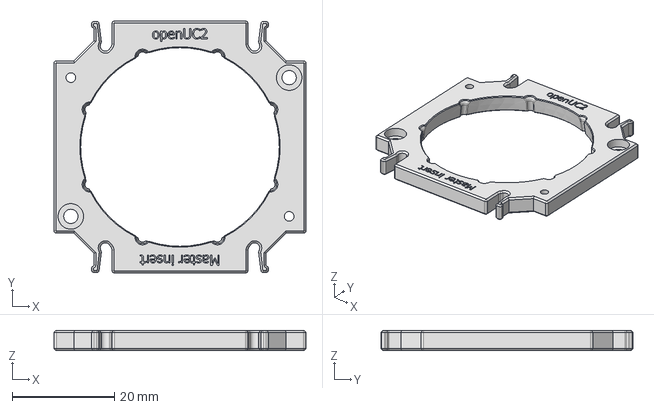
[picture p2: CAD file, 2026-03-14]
docs/dev/hw/module-inserts/v4/stp/PRT-2100-MASINS-V04-B.stp
49.4 x 49.4 x 4.00 mm

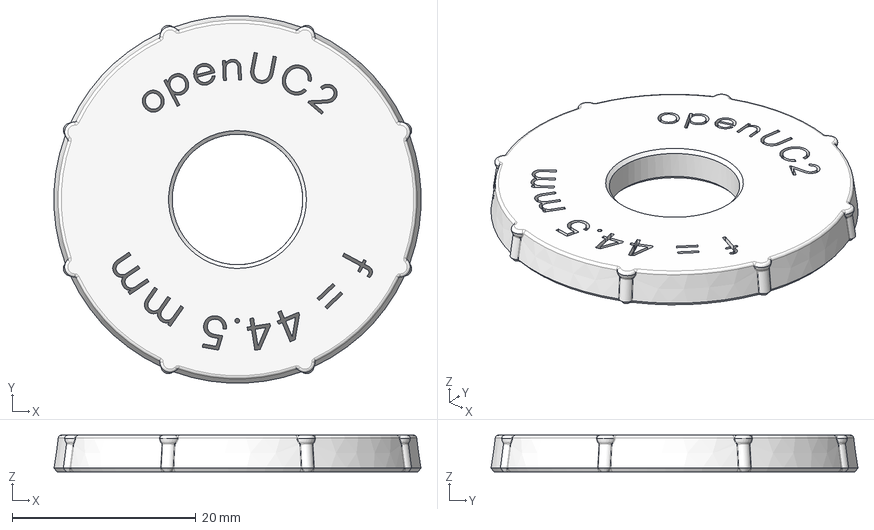
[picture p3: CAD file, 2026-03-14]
docs/dev/hw/module-inserts/v4/stp/PRT-2129-MASINSLEND16F44.5-V04-A.stp
39.9 x 39.9 x 4.00 mm

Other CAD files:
docs/dev/hw/module-inserts/v4/stp/PRT-2123-MASLCK-V04-B.stp

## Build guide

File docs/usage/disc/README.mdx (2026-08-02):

# Discovery Line

Modular, educational kits to explore optics — from basics to advanced microscopy and quantum experiments.

Each Box builds on the previous one, forming a progressive learning path from classical lens experiments to laser-based quantum setups.

---

## CoreBox – *Entry-Level Education Box*

The foundation of the UC2 Discovery Series.
Perfect for classrooms, workshops, and self-learners.

**What you’ll learn:**

* Basic principles of geometric optics
* How to build a lens, telescope, and simple microscope
* Puzzle-based assembly of components

**Included experiments:**

* Focal length measurement
* Telescope assembly
* Smartphone microscope

📄 [Documentation →](./corebox/index.md)

---

## ElectronicsBox – *Enhance with Interactivity*

Expands the CoreBox with electronics modules to enable illumination and motion control.

**What you’ll learn:**

* Working with microcontrollers (e.g., ESP32)
* Digital phase contrast with LED arrays
* Motorized Z-stage for focus control

**Included modules:**

* LED Matrix
* Motor driver + linear stage
* Neopixels + touch buttons

[Documentation →](./electronics-addon/README.md)

---

## 🔬 InfinityBox – *Camera-Based Imaging*

Adds optical components for infinity-corrected microscopy.

**What you’ll learn:**

* How to use objective lenses in an infinity-corrected system
* Aligning tube lenses and cameras
* Capturing digital images with CMOS sensors

**Compatible with:**

* USB microscopes
* Daheng / HIK industrial cameras

[Documentation →](./infinity-addon/README.md)

---

## FluoBox – *Fluorescence Microscopy*

Expands on the InfinityBox with fluorescence modules.

**What you’ll learn:**

* Excitation/emission principles
* Filter cube design
* Using lasers or high-power LEDs for illumination

**Experiments:**

* Visualizing stained samples
* Building a basic epifluorescence microscope

📄 [Documentation →](./fluorescence-addon/README.md)

---

## LightSheetBox – *3D Imaging of Transparent Samples*

Create a laser-based light-sheet microscope using XYZ motion.

**What you’ll learn:**

* Optical sectioning via light sheet illumination
* Using linear stages for scanning
* Working with cylindrical lenses

**Included modules:**

* Galvo or mirror scanning
* Fluorescence + sheet shaping optics
* Motorized XYZ movement

📄 [Documentation →](./lightsheet-addon/README.md)

---

## QBox – *Quantum & Interference Experiments*

Explore the wave nature of light and the quantum world.

**Experiments:**

* Michelson & Mach-Zehnder Interferometer
* Brewster angle and polarization
* Newton’s rings
* Holography-based reconstruction

**What you’ll learn:**

* Optical coherence
* Interference and diffraction
* Digital holography

📄 [Documentation →](qbox/README.mdx) {/* build:exclude=minimal */}
📄 [Documentation →](https://docs.openuc2.com/usage/disc/qbox/) {/* build:exclude=full */}

---

## Seeed Microscope – *Autonomous Smart Microscope*

Built with Seeed Studio — a ready-to-use, standalone microscope.

**Features:**

* Raspberry Pi or ESP32 based
* Autofocus + timelapse
* Local image storage on SD card
* Controlled via Wi-Fi or USB

**Ideal for:**

* Hackers
* Field biologists
* Schools and maker spaces

📄 [Documentation →](./xiao-microscope/README.md) {/* build:exclude=minimal */}
📄 [Documentation →](https://docs.openuc2.com/usage/disc/xiao-microscope/) {/* build:exclude=full */}

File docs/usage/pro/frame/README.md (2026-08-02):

# FRAME

Welcome to the documentation for the openUC2 **FRAME** — a fast, automated microscope
with fixed optics and a moving sample, built on open hardware, firmware, and software.

:::note Draft — audience router
TODO: turn this into three visual cards. For now, pick your path:

- **I'm setting one up** → [Day-1 tutorials](./tutorials/day-1/README.md)
- **I operate one (routine imaging)** → [Day-2 tutorials](./tutorials/day-2/README.md)
- **I'm building on it (hardware / apps / software)** → [Developers](./developers/README.md)
- **I'm deciding whether FRAME fits me** → [Explanations](./explanations/README.md)
:::

Our documentation is organized into:

- [Hands-on tutorials](./tutorials/README.md) to help you learn how to use the FRAME in an effective way.

  :::tip

  If this is your first time setting up a FRAME, please continue to our [day-1 tutorial](./tutorials/day-1/README.md), where you will learn how to deploy and use your FRAME.

  :::

- [How-to guides](./guides/README.md) to help you accomplish practical goals with the FRAME, after you've finished our tutorials.

- [Reference guides](./reference/README.md) which you can consult for technical descriptions about our products & projects and how to use them

- [In-depth explanations](./explanations/README.md) to help you understand the FRAME's design, from the perspective of a user or operator of a FRAME machine.

  :::tip

  If you don't have a FRAME yet and you're not sure whether a FRAME is the right solution for you, please continue to our [explanations](./explanations/README.md) of the FRAME's design and what problems it solves.

  :::

- [Developer documentation](./developers/README.md) for building on the FRAME: hardware
  add-ons, application/workflow integration (REST API, Python), and extending the
  ImSwitch control software.

- [Add-ons](./addons/README.md): optional hardware modules for the FRAME.

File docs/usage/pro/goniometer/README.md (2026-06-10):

# openUC2 Goniometer – Tutorial

Measure sessile-drop contact angles with your **openUC2 modular microscope** running **ImSwitch** on a Raspberry Pi.

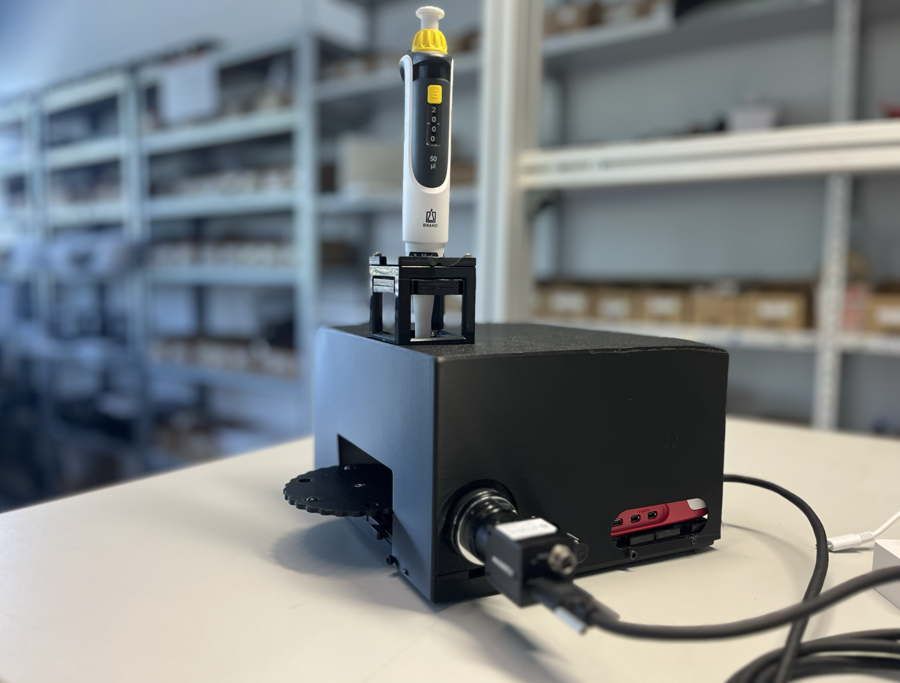
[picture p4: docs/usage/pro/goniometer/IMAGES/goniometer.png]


Beware: There are cubes inside :)

## 1. Hardware Overview

```
              ┌─────────────────────────────┐
              │      openUC2 Cube "Stack"   │
              │                             │
              │  ┌──────────┐               │
              │  │ Pipette  │  (syringe or  │
              │  │ Holder   │   dispenser)  │
              │  └────┬─────┘               │
              │       │ droplet             │
              │  ══════════════  substrate  │
              │                             │
              │  ┌───────────┐              │
              │  │HIK IMX178 │ USB3 camera  │
              │  │ CCTV Lens │  ~90° to drop│
              │  │    25 mm  │              │ 
              │  └───────────┘              │
              │                             │
              │  ┌──────────────────────┐   │
              │  │ LED Array + Diffuser │   │
              │  │  (back-light)        │   │
              │  └──────────────────────┘   │
              └─────────────────────────────┘
                        │ USB3
              ┌─────────▼──────────┐
              │   Raspberry Pi 5   │
              │   running ImSwitch │
              └────────────────────┘
                        │ Wi-Fi / Ethernet
              ┌─────────▼──────────┐
              │  Browser (laptop)  │
              │  ImSwitch UI       │
              └────────────────────┘
```

| Component | Details |
|---|---|
| **Platform** | openUC2 modular cube system |
| **Controller** | Raspberry Pi 5 (runs ImSwitch) |
| **Camera** | HIK Vision IMX178 (USB 3.0, 6.4 MP, colour/mono) |
| **Illumination** | LED array + diffuser — back-lit, homogeneous |
| **Dispensing** | Syringe pipette held in a cube mount; drops ~1–10 µL |
| **Substrate** | Flat sample placed on the cube base plate |

The camera observes the droplet from the side (macro view) so the contact line between the drop and substrate is visible as the widest horizontal extent of the drop silhouette.

## 2. Software Stack

```
Raspberry Pi
└── ImSwitch  (Python, FastAPI REST)
    └── GoniometerController  (plugin)
        ├── REST API  /GoniometerController/…
        └── OpenCV image processing pipeline

Browser
└── ImSwitch Frontend  (React)
    └── GoniometerController.js  (this UI)
```

ImSwitch exposes the goniometer as a REST API.
The React frontend is served alongside ImSwitch and communicates over the
local network.

## 3. In Action 

The software workflow is explained in the following video. You have to connect to the Raspberry Pi's wifi or network (PW: `youseetoo`) and then navigate to the website http://192.168.4.1 and enable the Goniometer app in the side bar:

<iframe width="560" height="315" src="https://www.youtube.com/embed/i9ORYjFVBrc?si=PmFjd52UPWCQaZsi" title="YouTube video player" frameborder="0" allow="accelerometer; autoplay; clipboard-write; encrypted-media; gyroscope; picture-in-picture; web-share" referrerpolicy="strict-origin-when-cross-origin" allowfullscreen></iframe>

## 4. UI Walkthrough

The code for the backend is here:
https://github.com/openUC2/ImSwitch/blob/master/imswitch/imcontrol/controller/controllers/GoniometerController.py

The code for the frontend is here:
https://github.com/openUC2/ImSwitch/blob/master/frontend/src/components/GoniometerController.js

### 4.1 Live Camera Stream

The top-left card shows a **live MJPEG stream** from the HIK camera.

- The stream is updated continuously — use it to position the pipette and
  focus the droplet before snapping.
- Zoom and pan are available on the **snapped image** (bottom card), not on
  the live view.

### 4.2 Setting a Crop ROI

For best results the algorithm only sees the droplet and its reflection — crop
out any background clutter.

1. Click the **Crop icon** (✂) in the live stream card header.
   The cursor changes to a crosshair and an info banner appears.
2. **Click and drag** a rectangle around the droplet (include a little
   background above and below).
3. Release the mouse — the crop is sent to the backend and a gold dashed
   rectangle persists on the live view.
4. To remove the crop, click the **×** on the orange "Crop active" chip, or
   click **Reset Crop**.

> **Why crop?** The algorithm searches for the widest contour in the image.
> Bubbles, pipette edges, or substrate edges that extend further than the drop
> width will confuse the baseline detection.

### 4.3 Camera Settings

Below the live stream you find two fields:

| Field | Typical value | Effect |
|---|---|---|
| **Exposure (ms)** | 2 – 10 ms | Shorter = less motion blur; too short = dark image |
| **Gain** | 0 – 10 | Amplifies signal; higher gain adds noise |

Press **Enter** or click outside the field to apply.
A well-exposed image shows a bright, uniform background and a clearly dark
drop silhouette.

### 4.4 Snap an Image

Click the green **Snap** button.

- The backend captures a full-resolution frame from the HIK camera.
- If a crop ROI is active, only the cropped region is returned.
- The snapped image appears in the lower card.
- The raw image is also saved as a TIFF on the Raspberry Pi
  (`/tmp/goniometer_*.tiff` by default).

### 4.5 Automatic Measurement 

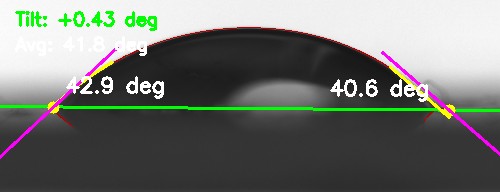
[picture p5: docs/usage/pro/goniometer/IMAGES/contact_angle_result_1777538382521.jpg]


After snapping, switch to the **Auto** tab (right panel) and click
**Measure (Auto)**.

The algorithm runs in ~100 ms and overlays:

- **Green line** — detected substrate baseline.
- **Cyan circles** — left and right contact points.
- **Cyan curves** — polynomial fit along each drop edge.
- **Magenta lines** — tangent vectors at the contact points.
- **Angle labels** — left angle θ_L and right angle θ_R in degrees.
- **Top-left overlay** — mean angle and wetting regime
  (*hydrophilic* θ < 90° or *hydrophobic* θ > 90°).

The results (θ_L, θ_R, baseline tilt, regime) appear in the panel on the
right.

### 4.6 Manual Measurement

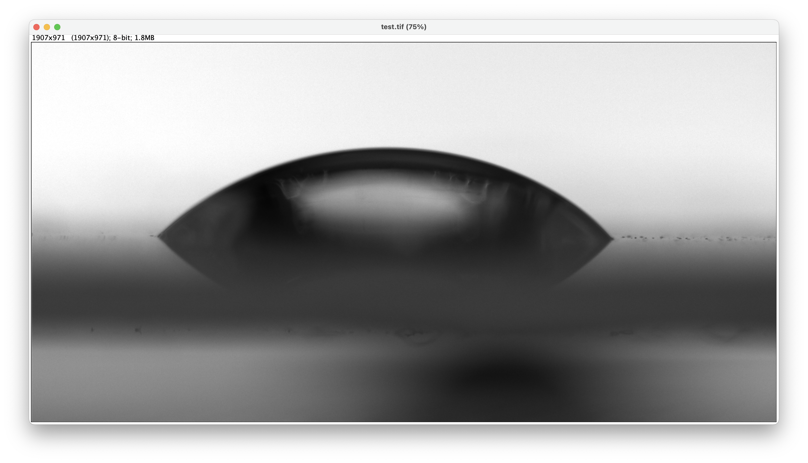
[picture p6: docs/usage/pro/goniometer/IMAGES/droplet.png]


For difficult cases (very small drops, contaminated substrates) use the
**Manual** tab.

You place **3 points** on the snapped image:

| Point | How to place | Purpose |
|---|---|---|
| **Baseline 1** | Click on the substrate, left of drop | Defines substrate line |
| **Baseline 2** | Click on the substrate, right of drop | Defines substrate line |
| **Tangent** | Click on the drop edge at the contact point | Direction of drop wall |

**Step-by-step:**

1. Switch to the **Manual** tab.
2. Click **Place Points** to enter placement mode (cursor → crosshair).
3. Click three times in the order above.
   Small numbered markers appear on the image.
4. Click **Measure (Manual)**.
   The angle is computed from the angle between the baseline vector and the
   tangent vector. The result is shown immediately.

> **Tip:** Zoom in (use the +/− buttons or scroll) and pan (click-drag) before
> placing points for higher accuracy.

### 4.7 Focus Monitor

Enable the **Focus Monitor** toggle in the right panel.
Every 500 ms the backend computes the **Laplacian variance** (sharpness) of
the live image and sends it back.

A progress bar shows the value relative to the session maximum.
Maximize it while turning the focus ring (or the z-stage) to get the sharpest
possible image before snapping.

### 4.8 Algorithm Configuration

Expand the **Config** section in the right panel to tune the image-processing parameters. You probably don't need to touch them anyway. 

| Parameter | Default | Effect |
|---|---|---|
| **Canny Low** | 30 | Lower Canny hysteresis threshold — increase for noisy images |
| **Canny High** | 100 | Upper Canny threshold — decrease to detect weaker edges |
| **Blur Kernel Size** | 5 | Gaussian pre-blur (odd numbers only) — reduce for sharp images |
| **Local Fit Fraction** | 0.15 | Fraction of drop width used for the tangent polynomial fit |
| **Polynomial Degree** | 2 | Degree of the tangent polynomial (2 = parabola, higher = more flexible) |
| **Tangent Delta (px)** | 1 | Finite-difference step for tangent evaluation |
| **Angle Min (°)** | 1 | Measurements below this are discarded as noise |
| **Angle Max (°)** | 179 | Measurements above this are discarded as noise |

Click **Reset Config** to return all values to defaults.
Changes are sent to the backend immediately and applied on the next measurement.

### 4.9 Measurement History & Export

Every successful measurement can be added to the session history:

1. After a successful auto or manual measurement click **Add to History**.
2. The history table shows: ID, time, mode, θ_L, θ_R.
3. The panel also shows a running **mean ± std** across all recorded values.
4. Use **Export CSV** or **Export JSON** to download the full table.
5. Click the download icon (↓) in the image card to save the annotated result
   image as a PNG.

## 5. Measurement Algorithm Explained

The algorithm is fully automatic and adapts to the wetting regime.

### 5.1 Preprocessing

1. The snapped frame is down-scaled so its longest edge ≤ 800 px (speeds up
   processing without losing accuracy at typical droplet sizes).
2. A Gaussian blur (kernel = `blur_ksize`) suppresses pixel noise.

### 5.2 Edge Detection & Contour Extraction

Canny edge detection produces a binary edge map.
The largest contour (by bounding-box width) is assumed to be the drop
silhouette including its mirror reflection in the substrate.

### 5.3 Wetting Regime Detection

The contour is profiled row by row to get width vs. vertical position.
The profile is smoothed and the maximum-width row (equator) is found.

- **Hydrophilic (θ < 90°):** No waist below the equator. The two widest
  points are the contact points; a tilted baseline is fitted through them.
- **Hydrophobic (θ > 90°):** A width minimum (waist) exists below the equator
  — the drop overhangs the contact line. The waist row defines the baseline.

```
  Hydrophilic              Hydrophobic
      ___                   _____
    /     \               /       \
   |       |          ___/         \___  ← equator (widest)
    \     /               ↑
  ───┴───┴───         ────┼────────      ← waist → baseline
   contact pts         contact pts
```

### 5.4 Polynomial Tangent Fit

For each contact point a short section of the drop edge
(length = `fit_frac × drop_width`) is fitted with a polynomial of degree
`poly_degree`. The tangent vector is evaluated by finite differences.

- **Hydrophilic:** polynomial y(x) — fit in the horizontal direction.
- **Hydrophobic:** polynomial x(y) — fit in the vertical direction (avoids
  near-vertical tangent issues).

The contact angle θ is the angle between the tangent vector and the baseline.

## 6. Step-by-Step Workflow

```
1. Power on Pi + camera + LED array
2. Open ImSwitch in browser
3. Navigate to Goniometer
4. Set Exposure & Gain → bright, sharp live image
5. Place substrate on base plate
6. Dispense droplet with pipette
7. Check live view — is the full drop visible?
8.   ├── Yes → proceed to step 9
8.   └── No  → adjust pipette height / substrate position
9. (Optional) Set Crop ROI around the drop
10. Focus Monitor ON → maximize sharpness
11. Click "Snap"
12. Inspect snapped image
13.  ├── Drop clearly visible → Auto Measure
13.  └── Poor contrast / noise → adjust Canny / blur, re-snap
14. Review annotated result
15.  ├── Correct baseline & tangents → Add to History
15.  └── Wrong detection → Manual Measure or retune Config
16. Repeat steps 6–15 for each measurement
17. Export CSV / JSON when done
```

## 7. Tips for Good Results

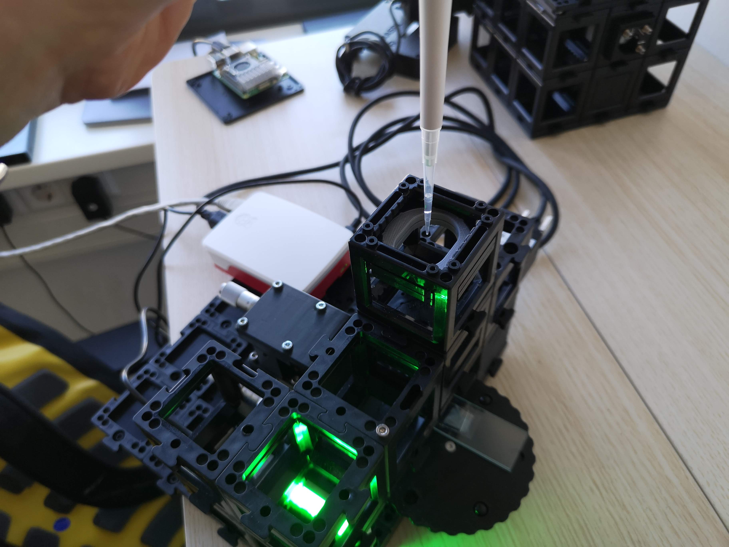
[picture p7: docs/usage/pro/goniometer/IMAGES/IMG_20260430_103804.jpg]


- **Back-lighting should be uniform.** The LED array + diffuser should produce a uniform   bright background so the drop appears as a solid dark silhouette.  Avoid reflections on the substrate surface.

- **Keep the baseline horizontal.** If the substrate is tilted, the algorithm   compensates (reports `baseline_tilt_deg`) but accuracy decreases for   large tilts. Use the cube  levelling feet.

- **Crop tightly but not too tight.** Leave ~20 px of background above the   top of the drop and below the substrate.   The mirror reflection (below the substrate) is NOT needed — only the real   drop is used.

- **Bring sample to focus.** Use the micrometer stage to place the droplet in the image plane 

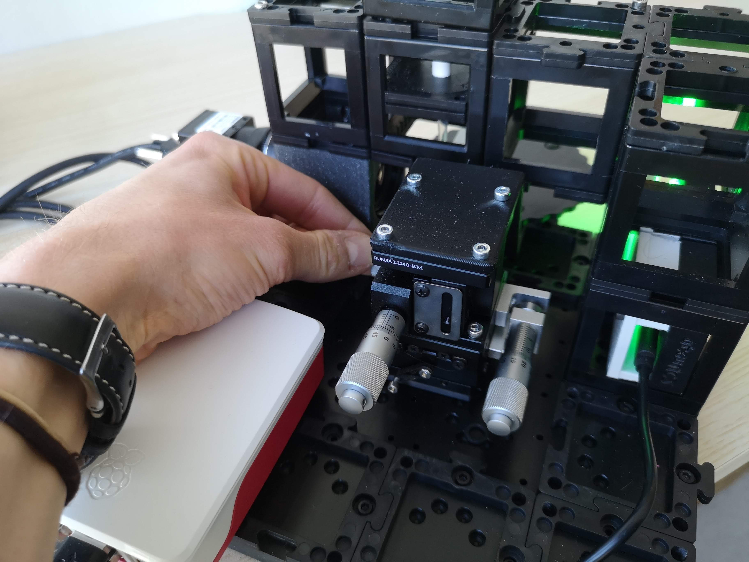
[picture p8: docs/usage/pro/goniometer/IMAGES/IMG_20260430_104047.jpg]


- **Repeat and average.** Dispense 5–10 drops and record each one.
  The mean ± std shown in the history panel is your reported contact angle.

## 8. Troubleshooting

| Symptom | Likely cause | Fix |
|---|---|-----|
| No live stream | Camera not detected by ImSwitch | Check USB3 cable; verify camera name in device config |
| "Detection failed" overlay | No contour found | Increase contrast (exposure, gain); check Canny thresholds |
| Wildly wrong angles | Wrong contour selected (pipette, edge) | Set crop ROI to isolate only the drop |
| Only one angle returned | Drop touches image border | Widen crop ROI or move drop into view |
| Hydrophobic/hydrophilic wrong | Waist threshold too sensitive | Increase `waist_rise_thresh` in DEFAULT_CONFIG (backend) |
| Baseline very tilted | Substrate not level | Level substrate; or use manual mode with explicit baseline |
| Focus bar stuck at low value | Wrong camera name | Verify detector name in ImSwitch config matches `GoniometerController` detector key |
| Export produces empty file | No measurements added to history | Click "Add to History" after each successful measurement |

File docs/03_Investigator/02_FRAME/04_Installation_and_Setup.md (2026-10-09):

# Installation and Setup

## Pre-Installation Checklist

Before beginning installation, ensure you have:

- [ ] Read all safety information in [Safety and Compliance](./01_Safety_and_Compliance.md)
- [ ] Verified environmental conditions meet specifications in [Technical Specifications](./03_Technical_Specifications.md)
- [ ] Prepared adequate workspace (minimum 1 m × 1.5 m)
- [ ] Organized necessary tools (see Tool Requirements below)
- [ ] Verified power supply compatibility in [Technical Specifications](./03_Technical_Specifications.md)

### Package Inspection

1. **Upon Delivery**:
   - Inspect packaging for damage during shipment
   - Document any visible damage with photographs
   - Check that all packages are received according to packing list

2. **Unpacking Procedure**:
   - Use proper lifting techniques (system weight: 25-35 kg)
   - Remove packaging materials carefully to avoid damage
   - Keep packaging materials until installation is complete
   - Verify all components against the packing list

### Standard Package Contents - Packing List 

#### Main System Components
- [ ] FRAME main unit (frame and base assembly)
- [ ] XYZ positioning system
- [ ] Illumination arm incl. light source (2x1 cubes)
- [ ] Control electronics unit
- [ ] camera
- [ ] Power supply for FRAME
- [ ] USB/CAN interface cables
- [ ] Camera cable
- [ ] USB-A to USB-C Cable
- [ ] Emergency Stop

#### Optical Components 
- [ ] Optical Module preconfigured (3x3x2 Cubes) 
- [ ] Objectives as ordered
- [ ] Camera interface adapter

#### Laser Module
- [ ] separate Laser module (3x2x1 cubes)
- [ ] Laser safety cover
- [ ] separate Laser (if applicable)
- [ ] separate Power supply for Laser (if applicable)
- [ ] Separate key

#### Accessories
- [ ] Sample holders and clips
- [ ] Biological test specimen
- [ ] Calibration target
- [ ] Ruler Target
- [ ] PS4-Controller
- [ ] Tool kit
- [ ] Documentation package
- [ ] Software installation media/download links

### Tool Requirements

#### Essential Tools
- Allen key set (2, 3, 4, 5, 6 mm)
- Phillips head screwdriver
- Flathead screwdriver
- Adjustable wrench
- Digital multimeter (for electrical verification)

#### Optional Tools
- Optical cleaning supplies
- Antistatic wrist strap
- Digital level
- Vibration measurement device

## Unpacking


*Take Case wrapped in bubble foil out of cardboard box.*


*Case, that holds the FRAME inside, with bubble foil removed.*


*Carefully open the case and ensure that there is no outer damage to the package. Store this case carefully and reuse it if necessary - it's a great suit case :)*



*Remove the Transport lock on top of the FRAME.* 


*The FRAME is covered with packaging material, foam and bubble foil, unwrap the parts and take out the components, starting with the smaller parts, including the illumination arm. The FRAME body itself is very heavy, so please make sure you get additional support and move the box out of the suitcase carefully. Hold it from the lower end* **don't lift it holding the Z-stage!**, *put this on a surface that is decently stable!*


**Don't forget to remove all foam parts inside the stage.** 

## Frame Positioning and Setup

### Initial Frame Positioning

1. **Position Main Frame**:
   ```
   ⚠️ CAUTION: Use proper lifting techniques. Two-person lift recommended.
   ```
   - Place frame on designated work surface

2. **Level the System**:
   - Use bubble level or digital level
   - Adjust position on surface until level in both X and Y directions
   - Verify stability by gently pressing corners
   - Re-check level after 30 minutes

3. **Surface Requirements**:
   - Stable, level surface capable of supporting 50 kg
   - Minimal vibration environment
   - Place away from air conditioning vents and heat sources
   - Good lighting for assembly work

4. **Power Requirements**:
   - 230V AC, 50/60 Hz power outlet (or 115V with adapter)
   - Dedicated circuit recommended
   - Power outlet within 2 meters of installation location
   - Proper grounding required

5. **Environmental Conditions**:
   - Temperature: 15°C to 35°C
   - Humidity: 30% to 80% RH, non-condensing
   - Clean environment, minimal dust

## Component Installation

### Mounting the Illumination Arm


*We start by mounting the illumination arm with the two M5 screws. For this get an appropriate 4mm allen key and secure the two screws that are sitting in the back of the frame and then attaching the illumination arm on the back. It's easiest if you have a second person holding the illumination arm and the second person is tighenting the screws. You can use a cube to have a spacer between the stage and illumination arm.*


*Ensure the illumination arm is in its highest position*


*Attach the CAN bus cables from the illumination arm to the electronics board by plugging them into the junction board*


*Secure the cable and optionally add the protective lid*


*Opening the rear box unveils the CAN Relay board which can be used to add additional components like Motors, etc*

**Getting electronics to work**


*Plugging in the Emergency stop (Audio Jack) into the rear electronics that controls the microscope. Plug it into the slot with the audio jack that says emergency stop*. **Activate the emergency stop by pressing it**


*Connect the ESP32 control board that runs the UC2 Firmware (youseetoo.github.io) with the Raspberry Pi using the USB-C to USB-A cable (you can either use the blue USB3 or black USb2 slots)* 


*Mount the USB3 Camera cable and lock the screws on the camera side*


*Mount the USb3 Camera cable on the Raspberry Pi side (use the blue USB3 slot)*


*Plug in the power suppy (12V) into the 12V jack on the Electronics side. Add the power socket (110/230V) cable and add this to the wall socket*


*Release the emergency stop to add 12V to the Frame*


*The power indicators on the relay boards should show 12V by letting the green LED light up*

**Initial System Testing**

The PS4 controller and web interface operations are covered in detail in the [Operation Manual](./05_Operation_Manual.md).

### System Function Tests

1. **Mechanical Systems**:
   - Test all axis movements (X, Y, Z, A)
   - Verify position accuracy and repeatability
   - Check travel limits and home positions
   - Test emergency stop functionality

2. **Electrical Systems**:
   - Verify power indicators (green LEDs)
   - Test CAN bus communication
   - Check camera connectivity and image acquisition
   - Confirm illumination control

### Mounting Optics


*Unbox the objective lenses and insert them in the dedicated slots by screwing them into the RMS Threads. Remove the stickers from the objective mounts before. Be careful not to touch the surfaces*


*Do the same for objective #2. The order depends on the configuration you have and must be mirrored in the configuration file.*

### Configuration File Setup

The objective order and other system parameters must be properly configured in ImSwitch. A complete sample configuration file is provided at:

📁 **Configuration File**: [`config_examples/FRAME_ImSwitch_Configuration.json`](./config_examples/FRAME_ImSwitch_Configuration.json)

This configuration file contains:
- Camera settings and detection parameters
- Laser and LED configurations
- Stage positioning and movement parameters
- Objective definitions and magnifications
- Available widgets and software components

You can also reference the online configuration repository:
🔗 https://github.com/openUC2/ImSwitchConfig/blob/master/imcontrol_setups/FRAME2.json

## Software Installation and Configuration

### Prerequisites

Before installing software locally, note that FRAME systems can be operated via:
- **Web Interface**: Direct browser access to the Raspberry Pi (recommended for most users)
- **Local Installation**: Install ImSwitch locally for advanced users or development

### Local Software Installation (Advanced Users)

If you need to install ImSwitch locally on your computer:

1. **Driver Installation**:
   - Install camera drivers (HikVision or compatible)
   - Install motor controller drivers (ESP32-based)
   - Install the USB-serial driver of the ESP32 board (CP2102 or CH340); the CAN bus needs no driver on the PC
   - Verify device manager shows all devices properly

2. **Control Software Installation**:
   - Download latest ImSwitch software from [GitHub](http://github.com/openuc2/imswitch)
   - Install the `UC2-REST` Python package (`pip install UC2-REST`; ImSwitch normally pulls it in)
   - Configure system parameters using provided configuration files
   - Load device configuration files (see [config_examples/](./config_examples/README.md))

### Initial Configuration

1. **Hardware Configuration**:
   - Define axis orientations and directions (see coordinate system reference)
   - Set travel limits and home positions
   - Configure camera parameters (exposure, gain, etc.)
   - Calibrate stage positioning using calibration target

2. **User Interface Setup**:
   - Configure display preferences and layouts
   - Set default acquisition parameters
   - Create user profiles for different operators
   - Configure safety interlocks and emergency stops

## Laser Module Installation and Safety

### Laser Safety Overview

⚠️ **CRITICAL SAFETY INFORMATION**

Laser safety is paramount when working with the FRAME system. The device incorporates multiple safety mechanisms to ensure Class 1 laser operation, meaning no dangerous radiation can escape the device enclosure when properly assembled.


*add the laser cover at the side*


*Secure the laser cover by snapping it in place*

### Safety Mechanisms

The FRAME incorporates three primary safety systems:

1. **Sample Lid Interlock**:
   - Laser-blocking lid with integrated safety switch
   - Must be properly positioned to activate laser systems
   - Prevents light from escaping through the objective lens

2. **Key Switch Interlock**:
   - Physical key switch that must be activated to enable laser operation
   - Provides positive control over laser activation

3. **Internal Interlocks**:
   - Monitors proper positioning of laser cover and internal components
   - Automatically disables laser if components are not properly installed

### Safety Procedures

**Before Operating with Lasers:**
1. Familiarize yourself with all safety features
2. Ensure all interlocks are functional
3. Verify proper assembly of all safety components
4. Check for any reflective surfaces in the beam path
5. Ensure proper ventilation and lighting in work area

**Emergency Procedures:**
- In case of power loss or interlock interruption, lasers automatically shut down
- Use the key switch to clear interlocks after addressing any safety issues
- Contact support if any safety mechanism appears damaged

### Laser Module Installation Procedures

#### Step 1: Prepare Laser Safety Lid


*Connect the laser safety lid cable to the interlock system*

#### Step 2: Install Sample Safety Lid


*The laser safety cover attaches magnetically to the four mounting points on the sample stage. The safety switch activates only when the lid is properly positioned.*


*Orient the openUC2 logo so it can be read when standing in front of the device*

#### Step 3: Install Laser Module Assembly


*The laser interlock and control unit can be removed from the main body similar to the optics cube. It contains the CAN bus adapter and internal safety interlocks.*


*Locate the internal laser interlock switch on the opposite side of the module*


*Slide the laser module into position from the side*


*Secure the laser module using the knurled locking screws*

#### Step 4: Connect Laser Module


*Connect the laser module to the CAN bus using the provided cable*


*Connect the CAN bus cable to the electronics box similar to the illumination unit*


*Power indicator: Green LED confirms the laser module is receiving power. The hardwired interlock system requires active key switch activation before laser operation is possible.*

**⚠️ SAFETY REMINDER**: Before activating the key switch, ensure there are no unprotected reflective surfaces in the beam path that could redirect laser light.

#### Step 5: Laser Connection (External Laser Configurations)

*Note: The following steps apply only to external laser configurations. Internal laser modules may not require these connections.*


*Connect the laser control cable from the laser module to the external laser*


*Verify correct wiring of the external laser control box*


*Connect the external 12V power supply for the laser system*


*Verify proper wiring configuration on the laser module*

#### Step 6: Fiber Optic Installation


*Insert the fiber optic cable into the screw terminal fiber mount*


*Carefully remove the protective cap and insert the fiber into the ferrule. Secure with the fiber holder nut.*

**⚠️ FIBER SAFETY**: Never touch the fiber end face as this may damage the core and degrade light transmission.


*Completed laser installation (configuration may vary depending on internal vs. external laser setup)*

**Dealing with the Sample calibration target**

For information about using the sample calibration target, see the [Operation Manual](./05_Operation_Manual.md) section on calibration procedures.

## Software Installation and Configuration

**Work In Progress**: This is for the case if you want to install imswotch locally..

### Step 1: System Software Installation

1. **Driver Installation**:
   - Install camera drivers
   - Install motor controller drivers
   - Install communication interface drivers
   - Verify device manager shows all devices

2. **Control Software Installation**:
   - Download latest ImSwitch software
   - Install the `UC2-REST` Python package (`pip install UC2-REST`)
   - Configure system parameters
   - Load device configuration files

### Step 2: Initial Configuration

1. **Hardware Configuration**:
   - Define axis orientations and directions
   - Set travel limits and home positions
   - Configure camera parameters
   - Calibrate stage positioning

2. **User Interface Setup**:
   - Configure display preferences
   - Set default acquisition parameters
   - Create user profiles
   - Configure safety interlocks

## Optical Alignment and Calibration

## Optical Alignment and Calibration

Proper optical alignment is critical for optimal system performance. The FRAME system requires alignment of multiple optical components to achieve proper imaging quality.

### Overview of Alignment Process

The optical alignment involves three main steps:
1. **Internal Optics Cube Preparation** - Align the removable optics cube outside the FRAME
2. **FRAME Integration** - Align the cube's optical axis with the FRAME system
3. **Final Verification** - Test and validate all optical paths

### Detailed Alignment Procedures

Complete step-by-step optical alignment procedures are provided in:

📁 **Reference Document**: [`config_examples/Optical_Alignment_Procedures.md`](./config_examples/Optical_Alignment_Procedures.md)

This document covers:
- Internal optics cube preparation and Köhler illumination setup
- Mechanical alignment using adjustment screws
- FRAME integration and axis alignment
- LED alignment tool setup and usage
- Position storage and calibration
- Troubleshooting common alignment issues

### Quick Alignment Summary

1. **Prepare Internal Cube**:
   - Remove optical module from FRAME
   - Set up external alignment fixture
   - Align fluorescence path for Köhler illumination
   - Center laser beam exit from objective

2. **FRAME Integration**:
   - Install LED alignment tool
   - Align Y-axis using cube adjustment screws
   - Align X-axis using electronic positioning
   - Store objective positions in EPROM

3. **Verification**:
   - Test both transmitted and fluorescence paths
   - Verify image quality and uniformity
   - Confirm objective switching accuracy

## Stage Coordinate System and Calibration

The FRAME uses a well-defined coordinate system for precise positioning. Complete details about the coordinate system, calibration procedures, and reference points are provided in:

📁 **Reference Document**: [`config_examples/Coordinate_System_Reference.md`](./config_examples/Coordinate_System_Reference.md)

### Key Points:

- **Origin Position**: Corresponds to multiwell plate position A1
- **Calibration Point**: Center reference at xy = 63.5/46 mm
- **Maximum Travel**: 127 x 86 mm (suitable for multiwell plates)
- **Stage Resolution**: 0.3125 μm per step


*Calibration target with crosshair lines for center positioning*


*Stage coordinate system showing maximum travel range*


*Coordinate system directions and axis orientations*

### Step 1: Illumination Alignment

**Note: This section is under development. Complete procedures will be provided in future updates.**

**Transmitted Light Setup**:
   - Center LED illumination for uniform field coverage
   - Adjust condenser position for optimal focus (currently only one position - move the LED double cube module along the optical axis so that the brightfield LED is collimated)
   - Plexiglass insert will ensure that darkfield/phase contrast rings will pass through
   - Verify field uniformity across entire viewing area on the camera (if not homogeneous, the objective slot positions need to be recalibrated)

### Step 2: Focus System Calibration

**Note: Complete calibration procedures are under development.**

- System currently does not have an encoder, so it's wise to home the positions periodically to maintain absolute positioning capabilities
- The system does not track lost steps (e.g., when the stage runs into an endstop and slips steps)
- Execute focus system homing sequence using the home button in the main GUI
- **Coming soon:** Set appropriate software travel limits (via the `config.json`)
- Test and verify autofocus functionality (using the button in the main GUI)

### Step 3: Camera Alignment

1. **Camera Installation Verification**:
   - Confirm secure camera mounting to interface
   - Verify data cable connections
   - Test camera software recognition (MVS Software from HIK Robotics / Galaxy Viewer from Daheng Imaging on your host computer)
   - Verify proper image acquisition

2. **Optical Alignment Verification**:
   - Center camera field of view with optical axis
   - Adjust back focal distance for optimal focus
   - Verify image sharpness across entire field
   - Calibrate pixel size and magnification factors

### Step 2: Software Testing

1. **Basic Functions**:
   - Test image acquisition
   - Verify stage control
   - Test focus control
   - Check illumination control

2. **Advanced Features**:
   - Test automation sequences
   - Verify remote access
   - Check data export functions
   - Test user interface responsiveness

## Customization Options

### Customize the Objective Holder

**Note: Customization procedures are under development.**

The FRAME system supports custom objective holders for specialized applications. Contact support for custom configurations.

### Customize the Optical Layers

**Note: Layer customization procedures are under development.**

The modular cube system allows for custom optical configurations. Detailed procedures for creating custom optical layers will be provided in future documentation updates.

In a nutshell: the different layers of the FRAME can be constructed freely upon users needs. The current version has a 3x3x2 inner cube-array, but it can be adjusted to be longer in the Y direction (e.g. 3x5xN) and in the Z-direction by stacking additional layers and increasing outer pillars' height. The below layers demonstrate how a brightfield imaging setup with a simple folding mirror, a tube lens and a camera can be constructed. Additionally we have a fluorescence layer with a fiber holder, the optics to shape the beam and the kinematic dichroic to focus it in the back focal plane from the imaging objective.


*All necessary components - except mirror dicroic mirror of fluroescence layer*


*Constructing the Fluorescence Layer on top of the Brightfield layer to build a 3x3x2 cube-array*


*Adding Top Plate on top of the cube-array*


*Locking the whole cube-array with extended screws*


*Ensuring the screws have a tight fit across all layers*


*Ready to use cube-array that can be pre-alligned with optics on top*


*Insert pre-alligned 3x3x2 cube-array into the FRAME*

## Troubleshooting Installation Issues

### Common Mechanical Issues

| Problem | Possible Cause | Solution |
|---|---|---|
| Rough stage movement | Misalignment or debris | Check alignment, clean rails |
| Focus drift | Thermal expansion | Allow warm-up time, check mounting |
| Vibration | Unstable surface | Improve vibration isolation |

### Common Electrical Issues

| Problem | Possible Cause | Solution |
|---|---|---|
| No power to modules | Fuse blown or wiring error | Check fuses and connections of CAN bus cables |
| Communication errors | CAN-BUS termination | 120 Ω termination at both physical bus ends only (HAT+ v2: jumper JP801); see [Boards, roles & node IDs](../../dev/sw/interface/reference/boards-and-node-ids.md) |
| Motor not responding | Driver configuration | Check driver settings or reflash and reconfigure via youseetoo.github.io |

### Common Software Issues

| Problem | Possible Cause | Solution |
|---|---|---|
| Device not recognized | Driver not installed | Reinstall drivers |
| Communication timeout | Network configuration | Check IP settings |
| Image acquisition fails | Camera not configured | Verify camera settings |

---

*Continue to [Operation Manual](./05_Operation_Manual.md) for detailed operating procedures.*

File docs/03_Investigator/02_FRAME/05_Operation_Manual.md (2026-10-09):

# Operation Manual

## System Startup and Shutdown

### Daily Startup Procedure

1. **Pre-Startup Checklist**:
   - [ ] Verify workspace is clean and organized
   - [ ] Check that no objects obstruct moving parts
   - [ ] Ensure adequate ventilation around electronics
   - [ ] Verify environmental conditions are within specifications

2. **Power-On Sequence**:
   ```
   ⚠️ CAUTION: Always follow proper startup sequence to avoid damage.
   ```
   - Connect 12V power supply
   - Wait for system self-test to complete (LED indicators and homing on startup)

ToDo Armin 250813: LED Indicators beschreiben, nur sichtbare für den Kunden, woran erkennt der Kunde, dass der Selftest vorbei ist und okay ist?
Was sagen die LEDs aus
LEDs Laser Modul
LEDs connector Board
LED ESP32 grün blinkend
Rote LED am Netzteil => Netzteil angeschlossen
LAN Kabel LED
   - XY axes will home and move to 0,0 position (disable by setting `homeOnStartX:0` in configuration file)
   - Start computer and ImSwitch control software
   - Allow 15-minute warm-up period for thermal stability if placed in an incubator

3. **System Initialization**:
   - Access ImSwitch from your laptop/tablet browser using the microscope's IP address or hostname with port 8001
   - Verify communication with all modules
   - Turn on live stream
   - Move to an XY position
   - Check illumination systems
   - Verify video stream is working
   - Check sample focus and begin image acquisition

### Shutdown Procedure

1. **End-of-Session Tasks**:
   - Park objectives in safe position
   - Turn off illumination systems
   - Go to settings and push the shutdown button
   - Wait approximately 30 seconds
   - Remove power plug

2. **Power-Down Sequence**:
   - Cover system if in dusty environment

## Basic Operation (FRAME System)

The FRAME system is fully motorized and operated through software interfaces. All system control is achieved through:
- **ImSwitch Web Interface**: Primary graphical user interface accessible via web browser
- **PS4 Controller**: Alternative hardware interface for manual positioning and control

**Short Introduction PS4 Controller operation**
- FRAME powered on, Self Tests and homing done, ESP32 ready
- PS4 Controller connects via bluetooth
- PS4 Controller - not connected

WhatsApp Bild 2025-08-14 um 11 05 17_498f94de
PS4-Controller 

WhatsApp Bild 2025-08-14 um 11 05 17_d300ffc5
Light Bar (PS4 turned off)

WhatsApp Bild 2025-08-14 um 14 08 59_3c7d1f66
Light Bar PS4 Connected (red)

WhatsApp Bild 2025-08-14 um 14 04 31_b3826f29
Light Bar PS4 charging and NOT connected (yellow)

- Press Home button for a couple of seconds (triangular button between joysticks), light bar shortly blinks and then shows steady light = succesful connection
Test X/Y/Z movement and lamp on/off according to 
grafik

(X/Y and Z Joystick testet, A not implemented, Lamp on/off tested, Z buttons not tested (needs imaging))  

Turning off PS4 => press home button for roughly 30s 
If PS4 cannot connect light bar blinks for around 15s,then turns off
If connection gets lost, light bar tunrs off after around 5s.

**Basic Microscopy Setup**

#### Sample Preparation and Loading

1. **Sample Mounting**:
   - Clean sample holder thoroughly
   - Mount sample according to type:
     - **Standard slides**: Use slide clips
     - **Petri dishes**: Use dish holder
     - **Custom samples**: Use appropriate fixtures
   - Ensure sample is secure and level







2. **Sample Positioning**:
   - Use coarse XY adjustment to center sample
   - Adjust Z-position for initial focus
   - Use fine adjustments for precise positioning

Sample positioning can be performed using either the PlayStation controller or the web GUI. The GUI provides a sample map where you can click anywhere to move the microscope to that position. Periodically, you may need to recalibrate the absolute positioning system to ensure accuracy. Use the stage center calibration tool in the web GUI to perform this calibration process.

#### Illumination Setup

The FRAME system offers multiple illumination modes:

**Transmission Illumination**: A high-powered white LED mounted above the sample provides transmission lighting with a lens system for Köhler illumination. Concentric LED rings around the main LED enable various contrast mechanisms including phase contrast, darkfield, and oblique illumination. Each RGB LED can be individually controlled to enable advanced techniques like Fourier ptychography microscopy.

**Fluorescence Illumination**: Multiple fluorescence excitation options are available from below, including laser excitation combined with dichroic filters to illuminate the sample from below.

All illumination settings are accessible through the main GUI illumination controls.

1. **Transmitted Light (Brightfield)**:
   - Turn on LED illumination
   - Adjust intensity using the LED slider in the GUI
   - Currently there are no mechanisms to center the LED - alignment assumes it is concentric with the objective lens after proper setup
   - The illumination NA is predefined by the LED lens system
   - Different numerical apertures can be achieved by turning on/off different rings of the LED matrix

2. **LED Matrix Illumination Setup**:
   ```
   📝 NOTE: Köhler illumination provides optimal image quality.
   ```

**LED Matrix Operation**: The LEDs arranged concentrically around the high-power LED enable various contrast mechanisms including darkfield, quantitative phase contrast, and Fourier ptychography. These can also be used for annular intensity diffraction tomography.

   ```
   ⚠️ CAUTION: Running all LEDs in bright mode consumes ~20W and generates significant heat.
   The LED array will automatically shut off if temperature exceeds 100°C.
   Do not operate all LEDs simultaneously for extended periods.
   ```

Different illumination patterns can be selected from the LED Matrix menu in the UI:

**Darkfield Mode**: Set different LED ring diameters to match numerical apertures just above the detecting objective. This eliminates direct light (zero order) through the objective lens, measuring only scattered light. This creates a dark background with bright sample features. Larger ring diameters correspond to higher numerical aperture values.

**Quantitative/Differential Phase Contrast**: Sequential activation of left/right and top/bottom LED patterns provides different information for computing sample phase relative to amplitude. This technique is useful for imaging transparent samples like unlabeled biological cells. After capturing four images, compute the differential phase contrast image by subtracting opposite sides and dividing by their sum. The system can automate this process and acquire images in sequence.

**Phase Contrast Ring**: Similar to darkfield, turn on the ring at a diameter matching the phase ring inside the objective. When the rings overlap properly, the zero order diffraction is dimmed, promoting phase variations in the sample. Proper alignment can be verified by observing the C-mount ring on the camera - you should see two concentric rings (one from the light, one from the objective). When these rings match in size and concentricity, a phase contrast image should appear.

### Focus Control

#### Coarse Focus
- **Range**: +/-4 mm vertical travel
- **Use**: Initial focusing and large adjustments
- **Technique**: Use smooth, controlled movements with the joystick or plus/minus buttons in the GUI
- **Safety**: Avoid contact between objective and sample - lens damage may occur!

Use the PlayStation controller's left joystick for up/down movement or the UI buttons for relative and absolute positioning.

#### Fine Focus
- **Use**: Precise focusing for high-magnification work using the rear paddles on the controller or reduced step size in the GUI
- **Technique**: Small incremental adjustments

Use the rear paddles on the PlayStation controller for precise objective lens movement or the GUI elements in the web interface for fine focus control.

### Stage Operation

#### Sample Navigation
1. **Initial Positioning**: Use coarse movements to locate area of interest
2. **Fine Positioning**: Use small adjustments for precise positioning
3. **Systematic Scanning**: Use consistent patterns for sample survey

Stage navigation can be performed using either the PlayStation controller or the web UI interface.

## Inner Cube System Operation

### Understanding the Inner Cube System

The FRAME microscope employs a unique modular cube drawer system that forms the heart of its optical configuration. The inner cube system consists of multiple cube holders that slide into the main optical frame, allowing for flexible optical path configuration.

**Note**: This section consolidates information about the inner cube system operation.

#### Cube System Components

1. **Cube Holders**: 50mm × 50mm × 50mm standardized mounting units
2. **Drawer Rails**: Precision sliding mechanisms for smooth cube insertion/removal  
3. **Optical Alignment System**: Ensures precise optical axis alignment
4. **Locking Mechanism**: Secures cubes in proper position during operation

### Inner Cube Assembly and Configuration

#### Pre-Assembly Inspection

Before installing any cube modules:

1. **Visual Inspection**:
   ```
   ⚠️ CAUTION: Handle cube modules carefully to avoid damage to optical surfaces.
   ```
   - Check cube holders for damage or debris
   - Verify drawer rails are clean and smooth
   - Inspect optical surfaces for cleanliness
   - Ensure all mounting screws are properly tightened

2. **Alignment Verification**:
   - Check that drawer rails are parallel to optical axis
   - Verify cube holder interfaces are square and clean
   - Test sliding motion without obstruction

#### Cube Installation Process

1. **Preparation**:
   - Power down the system completely
   - Ensure adequate workspace lighting
   - Have lens cleaning supplies readily available
   - Organize cube modules by intended position

2. **Installation Procedure**:
   ```
   Step 1: Open cube drawer system
   Step 2: Select appropriate cube module for position
   Step 3: Align cube with drawer guides
   Step 4: Slide cube into position until it clicks
   Step 5: Verify secure locking engagement
   Step 6: Test smooth drawer operation
   ```

3. **Position Verification**:
   - Check that cube sits flush in drawer
   - Verify optical alignment marks are aligned
   - Ensure no tilting or binding in drawer system
   - Test drawer sliding motion remains smooth

#### Standard Cube Configurations

##### Brightfield Configuration
- **Position 1**: Illumination cube (LED + condenser)
- **Position 2**: Sample holder cube  
- **Position 3**: Objective cube
- **Position 4**: Camera/detector cube

##### Fluorescence Configuration  
- **Position 1**: Excitation filter cube
- **Position 2**: Dichroic mirror cube
- **Position 3**: Emission filter cube
- **Position 4**: Detection cube

##### Phase Contrast Configuration
- **Position 1**: Phase condenser cube
- **Position 2**: Sample cube with phase rings
- **Position 3**: Phase objective cube
- **Position 4**: Camera cube

### Cube System Maintenance

#### Daily Maintenance (2 minutes)
- [ ] Visual inspection of cube alignment
- [ ] Check drawer sliding operation
- [ ] Verify secure locking of all cubes
- [ ] Clean any visible dust from cube surfaces
- [ ] Ensure the dichroic mirror is properly positioned

### Troubleshooting Common Cube System Issues

#### Cube Doesn't Slide Smoothly
**Symptoms**: Binding, sticking, or rough motion during cube insertion/removal

**Possible Causes**:
- Debris in drawer rails
- Misaligned cube holder
- Worn or damaged rail surfaces
- Improper cube orientation
- Loose screws

**Solutions**:
1. Clean drawer rails thoroughly with appropriate solvent
2. Check cube orientation and reinsert properly
3. Inspect for physical damage to rails or cube interfaces
4. Apply specified lubricant if recommended in maintenance manual

#### Optical Misalignment After Cube Installation  
**Symptoms**: Reduced image quality, vignetting, or focus issues

**Possible Causes**:
- Cube not fully seated in drawer (not reaching endstop)
- Improper cube orientation
- Damaged optical surfaces
- Contamination on optical interfaces

**Solutions**:
1. Remove and reinstall cube ensuring full seating
2. Verify cube orientation matches alignment marks
3. Clean optical surfaces using proper lens cleaning techniques
4. Check for damaged optical components requiring replacement

#### Cube Locking Mechanism Failure
**Symptoms**: Cube doesn't stay securely in position, can be easily moved

**Possible Causes**:
- Worn locking mechanism
- Debris preventing proper engagement

**Solutions**:
1. Clean locking mechanism thoroughly
2. Inspect locking interface for damage  
3. Contact technical support if mechanism repair is required (see our forum) 

### Safety Considerations for working on Inner Cube System 

```
⚠️ WARNING: Always power down system before cube manipulation
```

1. **Electrical Safety**:
   - Ensure system is completely powered off
   - Allow electronics to discharge before handling
   - Avoid touching electrical contacts on cube modules

2. **Optical Safety**:
   - Handle optical surfaces with extreme care
   - Use appropriate lens cleaning materials only
   - Never touch optical surfaces with bare hands
   - Store removed cubes in protective containers

3. **Mechanical Safety**:
   - Support cube weight properly during installation
   - Avoid forcing cubes into position
   - Check for secure locking before releasing cube
   - Keep fingers clear of drawer mechanisms

### Software Interface Overview

#### ImSwitch Control Interface

**Note**: This section provides an overview of the ImSwitch control interface. For detailed tutorials with images and videos, please refer to the current ImSwitch documentation.

The FRAME system integrates with ImSwitch software for comprehensive control:

1. **Main Interface Elements**:
   - **Live View**: Real-time camera display
   - **Stage Control**: XYZ positioning controls
   - **Illumination Control**: Light source intensity and switching
   - **Acquisition Settings**: Camera and recording parameters

**Additional Controllers**: Your custom system configuration can include various other controllers that merge different functionalities between hardware, image processing, and software, such as:

- **Autofocus Controller**: Takes a series of images while moving the stage and moves to the position with highest contrast
- **Experiment Controller**: Enables area scanning and stitching
- **Backend Controllers**: Provide functionality through the React-based web application

For up-to-date documentation, please refer to our ImSwitch documentation or repository.

2. **Navigation Panel**:
   - Position indicators with numerical readouts
   - Step size selection for movements
   - Home and limit position controls
   - Emergency stop button

**Calibration of Pixel Size by Capturing a Ruler**

The microscope does not know its physical properties, so we must calibrate the motion axes to convert from steps to millimeters and from pixels to millimeters. These values are stored in the configuration file but require initial calibration. For linear stages, this depends on hardware specifications and is already pre-configured.

When objective magnification changes, the effective pixel size changes and requires recalibration. To calibrate:
1. Take a ruler with known dimensions
2. Capture an image
3. Open the file in Fiji to measure the number of pixels for a given unit on the calibration slide
4. Calculate pixel size: divide the known distance (e.g., 1 millimeter) by the number of pixels (e.g., 1000 pixels) to get pixel size (1 micrometer in this example)

**Capturing a Large Panorama Using Multiple Tiles and Opening in Fiji**

The experiment controller has a built-in sample overview map where you can select an area using the max dome selector. This area is then scanned sequentially in XY to produce a stitched imaging result. 

#### PS4 Controller Operation

```
📝 NOTE: The FRAME system supports wireless PS4 controller for intuitive operation.
```


*PS4 controller for wireless operation. Press the connect button (middle button) and wait for the controller to connect to the microscope (will flash a few times and then glow continuously). For detailed function explanations, see: https://docs.openuc2.com/docs/Electronics/PS4-Controller/PS4-Controller/*

1. **Connection Setup**:
   - Press the connect button (middle button on controller)
   - Wait for controller to pair (LED will flash then remain steady)
   - Verify connection in system interface

2. **Control Functions**:
   - **Right Stick**: XY stage movement
   - **Left Stick**: Z-axis (focus) control (up/down)
   - **Rear Paddles**: Z-axis fine control (left/right paddles for up/down)
   - **Cross Button**: Turn on/off Laser 1/2
   - **Other Buttons**: Various system functions and shortcuts for LED ring control, photo capture

#### Web Interface Access

##### Web Serial

You can access the functions of the microscope using the serial interface. This works without any installation or the Raspberry Pi: connect a computer to the HAT+ USB-C port and open the [WebSerial test page](https://youseetoo.github.io/indexWebSerialTest.html) in Chrome or Edge. The HAT+ ESP32 (`UC2_canopen_master`) uses 921600 baud, and the port must not be in use by ImSwitch.


*Web serial interface showing device connection and control options. Use this interface to connect to the ESP32 device and test motion by moving the stage and controlling illumination remotely.*

##### Web Interface using ImSwitch

This interface is ideal for complex experiments where hardware, software, and image acquisition must work together.

```
📝 NOTE: The FRAME system includes a web-based interface for remote operation.
For more information: https://docs.openuc2.com/docs/ImSwitch/Quickstart
```

1. **Access Setup**:
   - Connect to system via browser: `http://[IP_ADDRESS]:8001`
   - Accept self-signed SSL certificate if prompted
   - Log in with user credentials

2. **Interface Features**:
   - Complete system control via web browser
   - Real-time image display
   - Parameter adjustment and automation
   - Data export and sharing capabilities

### Motorized Stage Control

#### Position Control
- **Resolution**: 0.3 μm minimum step size
- **Speed Range**: 0.1 μm/s to 10 mm/s
- **Acceleration**: Programmable acceleration profiles
- **Accuracy**: Position repeatability within specification limits

#### Movement Commands
1. **Absolute Positioning**: Move to specific coordinates
2. **Relative Positioning**: Move by specified distance from current position
3. **Homing**: Return to defined home position
4. **Limit Setting**: Define software travel limits

 For the underlying serial commands see [Serial commands](../../dev/sw/interface/reference/serial-commands.md#motor_act).

### Autofocus System

**This is a work-in-progress section**

#### Focus Methods

1. **Astigmatism-based Laser Focussing** (optional as a module):
   - Non-contact surface detection
   - Works with reflective samples
   - Fast response time
   - CAN-bus integration
   - IR detection
   - More information: https://github.com/openUC2/openUC2-Hackathon-BluFocus

2. **Image-Based Autofocus**:
   - Analyzes image contrast
   - Works with any sample type
   - Requires good illumination
   - Slower but more versatile
   - Implemented in the ImSwitch Software

### Illumination Control

#### LED System Control

**Note**: This section consolidates LED control information with the earlier illumination setup section.

1. **Intensity Adjustment**:
   - Software control: 0-100% intensity corresponding to PWM/TTL values from hardware
   - Real-time adjustment during imaging
   - Independent control of multiple channels
   - Automatic exposure compensation

2. **Multi-Channel Illumination** (Fluorescence):
   - Individual LED control
   - Wavelength selection
   - Filter coordination
   - Sequence programming

## Imaging and Acquisition

### Camera Operation

#### Basic Image Acquisition

**This is a work-in-progress documentation section**

1. **Live View Setup**:
   - Start camera streaming
   - Adjust exposure time and gain
   - Check for proper illumination
   - Verify focus quality

2. **Image Capture**:
   - Single image capture
   - Time-lapse sequences
   - Z-stack acquisition
   - Multi-channel imaging

#### Advanced Acquisition Modes

1. **Time-Lapse Imaging**:
   - Define acquisition intervals
   - Set total duration
   - Configure illumination timing
   - Monitor sample stability

2. **Z-Stack Acquisition**:
   - Define focus range
   - Set step size between planes
   - Configure acquisition sequence
   - Post-processing options

3. **Multi-Position Imaging**:
   - Define position list
   - Set acquisition parameters per position
   - Configure stage movement timing
   - Batch processing options

### Contrast Methods

#### Brightfield Microscopy

1. **Setup Procedure**:
   - Use white LED illumination
   - Set Köhler illumination
   - Adjust condenser aperture
   - Optimize contrast vs. resolution

2. **Optimization**:
   - Balance illumination intensity
   - Adjust aperture diaphragm
   - Check field uniformity
   - Fine-tune focus

#### Phase Contrast Microscopy

1. **Requirements**:
   - Phase contrast objectives
   - Phase rings in condenser
   - Proper alignment essential

2. **Setup Procedure**:
   - Install phase contrast condenser
   - Select matching phase ring
   - Align phase rings (centering telescope recommended)
   - Optimize aperture settings

#### Differential Phase Contrast (DPC)

1. **Requirements**:
   - Ring Led with multiple segments
   - Proper optical alignment

2. **Setup Procedure**:
   - Take images with illumination on left/right, up/down
   - compute

#### Fluorescence Microscopy

1. **Safety Considerations**:
   ```
   ☀️ WARNING: UV radiation hazard. Use appropriate eye protection. in case of lasers ensure you follow laser safety guidelines
   ```
   - follow Laser safety steps
   - Minimize any radiation that could harm you
   - Ensure proper ventilation

2. **Setup Procedure**:
   - Install appropriate filter sets (muss gleichli this is are the free installs as you have a multi and filter set
   - Select correct excitation wavelength 
   - Adjust illumination intensity
   - Optimize for signal-to-noise ratio by increasing or decreasing exposure time and gain

3. **Filter Sets**:
  country be provide laserbase exitation for the following Wrestling 

405, 488, 532, 635 nm

we plan to have led based exhortation to so please feel free to reach out to us if you need additional guidance

### Step-by-step guid for the FRAME Microscope to acquire fluorescence images

#### Walk through using multi-band fluorescence excitation in a hands-on session

<div style={{position: 'relative', paddingBottom: '56.25%', height: 0, overflow: 'hidden'}}>
  <iframe 
    style={{position: 'absolute', top: 0, left: 0, width: '100%', height: '100%'}}
    src="https://www.youtube.com/embed/WS8fe_PJkTk?si=lJT3H80CpWUPyPto" 
    title="YouTube video player" 
    frameBorder="0" 
    allow="accelerometer; autoplay; clipboard-write; encrypted-media; gyroscope; picture-in-picture" 
    allowFullScreen
  />
</div>

#### Walk through using multi-band fluorescence excitation in a hands-on session from the software perspective

<div style={{position: 'relative', paddingBottom: '56.25%', height: 0, overflow: 'hidden'}}>
  <iframe 
    style={{position: 'absolute', top: 0, left: 0, width: '100%', height: '100%'}}
    src="https://www.youtube.com/embed/AP0Lg3NQ5r4?si=lBYVk9zBTs0dbSTj" 
    title="YouTube video player" 
    frameBorder="0" 
    allow="accelerometer; autoplay; clipboard-write; encrypted-media; gyroscope; picture-in-picture" 
    allowFullScreen
  />
</div>

## Automation and Programming

### Basic Automation Scripts

#### Python Interface

##### ImSwitch-Client based

##### Jupyter notebook

##### As Controller

### Advanced Automation

#### Multi-Well Plate Imaging

*Docs Coming Soon* Inside the ImSwitch Wellplate Controller

#### Time-Lapse with Environmental Control

*Docs Coming Soon* Inside the ImSwitch Experiment Controller

## System Monitoring and Maintenance

### Performance Monitoring

#### System Health Checks

1. **Daily Checks**:
   - Verify stage positioning accuracy
   - Check focus repeatability
   - Monitor temperature stability
   - Test illumination uniformity

2. **Weekly Checks**:
   - Clean optical surfaces
   - Check mechanical adjustments
   - Verify software backups
   - Update system logs

### Preventive Maintenance

#### Daily Maintenance

1. **Optical Cleaning**:
   - Use appropriate cleaning materials
   - Clean in circular motions from center outward
   - Avoid touching optical surfaces with fingers
   - Use compressed air to remove dust

2. **Mechanical Care**:
   - Check for smooth stage movement
   - Verify focus mechanism operation
   - Clean sample holders
   - Organize workspace

#### Weekly Maintenance

1. **System Cleaning**:
   - Clean external surfaces with mild detergent
   - Vacuum air vents and cooling fans
   - Check cable connections
   - Update software if needed

2. **Calibration Verification**:
   - Check stage accuracy with calibration sample
   - Verify camera pixel calibration
   - Test autofocus repeatability
   - Document any deviations


*Sample calibration target for stage center calibration. This target helps calibrate the stage's center position. When moving to the stage center, the offset position should be X/Y=55/43mm.*

## Troubleshooting

### Common Issues and Solutions

#### Mechanical Problems

| Problem | Symptoms | Possible Causes | Solutions |
|---|---|---|---|
| Stage binding | Rough movement, positioning errors | Debris, misalignment | Clean rails, check alignment |
| Focus drift | Image goes out of focus over time | Temperature changes, loose connections | Allow warm-up, check mounts |
| Vibration | Image instability | Poor isolation, external vibration | Improve isolation, check environment |

#### Optical Problems

| Problem | Symptoms | Possible Causes | Solutions |
|---|---|---|---|
| Poor image quality | Blurry, low contrast | Dirty optics, misalignment | Clean lenses, check alignment |
| Uneven illumination | Dark or bright spots | Bulb misalignment, dirty condenser | Align illumination, clean optics |
| Focus problems | Cannot achieve sharp focus | Objective/sample mismatch | Check working distance, clean |

#### Software Problems

| Problem | Symptoms | Possible Causes | Solutions |
|---|---|---|---|
| Communication errors | Device not responding | Driver issues, cable problems | Reinstall drivers, check cables |
| Slow performance | Laggy interface | Insufficient resources | Close other programs, add RAM |
| Acquisition failures | Camera not capturing | Configuration errors | Check camera settings |

### Error Codes and Diagnostics

#### System Error Codes

- **E001**: Stage communication timeout
- **E002**: Focus limit reached
- **E003**: Camera initialization failed
- **E004**: Illumination system fault
- **E005**: Temperature out of range

#### Diagnostic Procedures

1. **System Diagnostic Mode**:
   - Access via service menu
   - Run automated tests
   - Review diagnostic reports
   - Contact support if needed

2. **Log File Analysis**:
   - Check system logs for errors
   - Monitor performance metrics
   - Track usage patterns
   - Export logs for support

---

*Continue to [Maintenance and Troubleshooting](./06_Maintenance_and_Troubleshooting.md) for detailed maintenance procedures.*

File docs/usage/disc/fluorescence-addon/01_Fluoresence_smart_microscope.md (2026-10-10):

---
id: LED_Fluoresence_microscope_V1
title: openUC2 LED Fluoresence microscope
---

# Tutorial: Building a Smart LED-Powered Fluorescence Microscope

In this workshop, we will guide you through assembling a LED-powered fluorescence microscope, allowing you to explore fascinating experiments with microscopic details.

### Materials Needed

1. Blue LED (for exciting fluorescence molecules).
2. LED Lid
3. LED-Matrix with USB-C cable (for bright-field microscopy)
4. Electronic Z-stage with some technical nobs
5. Mainboard with UBC-mini cable
6. PS4 Controller (for controlling the Z-stage)
7. Infinity objective
8. Beamsplitter
9. Aspherical lens (for beam collimation)
10. Biconvex lens (f' = 100mm, for focusing)
11. Diaphragm
12. Camera with tube lens
13. Probe insert
14. Probes
15. cubes and base plates

### Diagram



### Theory of Operation

Fluorescence is a photophysical process that describes the spontaneous emission of light shortly after an electron is excited to a higher-energy state.
First, an electron is excited from the ground state to the higher-energy state  through absorption. After a short time (approximately 10⁻⁹ s), the excited electron returns to the ground state, releasing energy in the form of radiation. Due to the Stokes-shift within the S₁ state, the emitted light has a longer wavelength (λ₂) than the radiation used for excitation (λ₁).



### Theoretical Background: Fluorescence

Fluorescence is a photophysical process that describes the spontaneous emission of light shortly after an electron is excited to a higher-energy state.
First, an electron is excited from the ground state to the higher-energy state  through absorption. After a short time (approximately 10⁻⁹ s), the excited electron returns to the ground state, releasing energy in the form of radiation. Due to the Stokes-shift within the S₁ state, the emitted light has a longer wavelength (λ₂) than the radiation used for excitation (λ₁).



## Tutorial: LED-Powered Fluorescence Microscope



### Step 1: Assemble the Microscope

This guide will walk you through building the microscope step by step. You can follow the assembly process according to the functional groups or refer to the diagram above.

#### 1.1: Assembling the Bright-Field Microscope

1. **Build the Baseplate**: This will connect the LED-matrix, probe insert, movable infinity objective, beamsplitter and the camera (which is already connected to the tube lens).Attach wo extra baseplates for the Z-stage.


2. **Attach the LED-matrix**: Place the LED-matrix and than the probe insert behind it, securing both with two baseplates on top.




3. **Install the movable Infinity-Objective**: Drill the objective into the objective mount of the electronic Z-stage. As you can see, there are two RMS-inserts for the Objective, how to choose the right one? In this assembly, because the Z-stage lays flat on the ground choose the insert thats closest to the Z-stage (50mm distance). As shown below the lettering "stage" is placed upward. The second option on the other side (55mm distance) you need when you built the microscope not flat laying, but standing on the ground. Why? Because then there will be an extra puzzle piece between the electronic z-stage and the objektive-mount, so to make shure the obejctive is still in fokus you need 5mm more distance to accomodate für the puzzle piece.
Lastly insert the technical pins on the long sides to attach the baseplates.


4. **Position the beamsplitter cube**: Insert the beamsplitter cube (you can leave it empty for now, it will be needed when assembling the fluorescence microscope).



5. **Add the camera**: Finally, attach the camera unit behind the beamsplitter and secure everything with a second layer of baseplates.





Now, your bright-field microscope is ready!

#### 1.2: Assembling the Fluorescence Microscope
But of course if you got this box you want more, so now let#s start buidling the fluorescene Microscope

1. **Prepare a 4x1 Baseplate**: After that, attach it to the beamsplitter cube.



2. **Position the Blue LED**: Place the blue LED at the furthest point from the beamsplitter. Place the LED lid in front of it, to reduce stray light.





3. **Collimate the Light**: The blue LED is a divergent light source, so use the aspherical lens to collimate the light. Your Box comes with a aspherical lens with eighter f'= 20mm or f' = 30mm.  Insert the diaphragm right next to it in the same cube. It's used as a field diaphragm and defines the size of the illuminated area and prevents unnecessary stray light outside the desired field of view.
Place the aspherical lens it's focal length away from the light source (20mm or 30mm), so that rays emerging from the focal point are rendered collimated.
Checking if a divergent light source such as a LED is collimated, is not as straight forward as it is with a laser so go [here](https://docs.openuc2.com/docs/Toolboxes/DiscoveryFluorescence/Alligment%20of%20the%20LED-Mikroscope) for an in Depth tutorial.





5. **Focus the Light**: To focus the collimated light into the objective, insert an empty cube, followed by the biconvex lens. The space between the aspherical lens and the biconvex lens should be the sum of their focal lengths. The aspherical lens has a focal length of 20mm, and the biconvex lens has 100mm, so you need approximately 120mm between the two.





6. **Insert the Beamsplitter**: Place the beamsplitter carefully. Make sure the filter sides are oriented correctly to avoid blocking the wrong wavelengths.





7. **Focus Light into the Infinity Objective**: to correctly focus the ligth into the infinity objective, position the biconvex lens and infinity objective with about 100mm of space between them.





After completing these steps, you're done with the assembly, nice job!

# Step 2: Turn Your Microscope Into a Smart One - aka the Electronics  

### 2.1: Plug in the Electronics as Shown Below

**⚠️ Caution!**
If you need to change any of the cables or their position, always unplug the 12V power cable before doing so. Otherwise, the electronic components might get damaged!

**⚠️**
These instructions based on the Pin-layout of the **ESO32-DEV-based UC2 standalone board V3 (beta)**)
find the Pin-layout for the **ESO32-DEV-based UC2 standalone board V4** [here](https://docs.openuc2.com/docs/Electronics/UC2StandaloneBoard/uc2e2v4)

- connect the LED-Matrix panel by plugging in the micro-USB and connect it to your PC.



- Connect the blue LED to the Mainboard at `PMW2`
  - The **GND** cable goes to `PMW2-GND`





- Plug in the micro-USB at your ESP32 and connect to your PC.



- Plug in the 12V power cable.



### 2.2: Flashing the ESP32 Firmware

1. Before proceeding, ensure your ESP32 board has the latest firmware. You can download and flash the firmware via the official [openUC2 website](https://youseetoo.github.io/), selecting **your version**, then click on the `connect` button. The source code can be found [here](https://github.com/youseetoo/uc2-esp32).

<p align="center">
<em>Flashing process shown for the ESP32-DEV-based UC2 standalone board V3 (beta).</em>
</p>



2. Connect the ESP32 to your computer using the micro-USB cable.  

3. In your Chrome browser, a dialog will prompt you to select the COM port for your ESP32, which should be shown as `CP2102 USB to UART Bridge Controller`. Once connected, you can install the latest firmware by simply clicking the "Install" button.
  

  

  If nothing shows up, you can install the drivers from the prompt that appears when you click anywhere on the screen:

   

4. Wait until the firmware has been successfully flashed.

5. &#x1F4A1; **flash your LED-matrix**. Repeat the same steps, but this time for the LED-matrix
   

**TROUBLE SHOOT: The firmware doesn't flash**

Sometimes the ESP32(s3) doesn't enter the bootloader. Then you have to first erase the flash and then flash the firmware. For this go here and follow the following steps: https://espressif.github.io/esptool-js/

- connect to the board
- erase flash
- wait
- refresh the page and free the serial connection



### 2.3: Connecting to the Web Interface
 (valid since March 2025)
1. After flashing the firmware, go to the testing section on the same website.

2. Connect to your ESP32 board using the `connect` button again, ensuring the correct COM port is selected.  

   

3. Once connected, test the system by sending a simple command:

```json
{"task":"/motor_act", "motor": { "steppers": [ { "stepperid": 3, "position": -1000, "speed": 1000, "isabs": 0} ] } }
```



This command will move the Z-axis motor by -1000 steps (1 full rotation) at a speed of 1000 steps per second. Each step corresponds to a movement of 300nm when using microstepping. You’ll observe the motor rotating, adjusting the focus.

**Note:** Ensure that the command string has no line breaks.

4. &#x1F4A1;**Connect your LED-matrix as well**. Duplicate the current tab and connect the LED-matrix again via the button. Choose the correct COM Port.  
Now you can test all components through these two tabs.

### 2.4: Testing in the Web Interface
(valid since March 2025)

1. After completing the test, go back to the first tab to control the other components via buttons:
   - `PMW2(on)` and `PMW2(off)` control the blue excitation LED.
   - `Motor Z(+)` and `Motor Z(-)` control the Z-stage.
   - `LED (on)` and `LED (off)` control the LED-matrix panel (&#x1F4A1;you must change tabs to control it).

### 2.5: Pairing the PS4 Controller &#x1F3AE;

The UC2-ESP firmware supports various input devices, including the PS4 controller, to make interacting with the microscope easier. While you've already worked with USB serial commands, using the PS4 controller offers a more flexible, hands-on approach. For more detailed instructions on pairing, refer to the [UC2 PS4 Controller Pairing Guide](https://docs.openuc2.com/docs/Electronics/PS4-Controller/PS4-Controller). Here’s a brief summary:

1. **Put your PS4 controller into pairing mode** by holding down the `Share` button and the `PS` button simultaneously until the light bar starts blinking.
2. Click the `Pair Controller` button in the web interface. Alternatively, open the serial prompt in your browser (connected to the ESP32 board) or use the web interface and enter the following command:

```json
{"task":"/bt_scan"}
```

  This will initiate the Bluetooth scan on the ESP32, which will detect and pair with the controller.

  Once paired, you can control the motorized stage using the analog sticks and switch the LED-matrix on/off using the buttons. The complete pinout of the different function you can find here: [UC2 PS4 Controller Pairing Guide](https://docs.openuc2.com/docs/Electronics/PS4-Controller/PS4-Controller) (valid since June 2025)

### 2.6: Setup and Use the Camera Software
Instructions for the HIKROBOT - Camera - MV-CE060-10UM-PRO:

1. Connect the camera to your PC.



2. For the installation process and useage of the software, follow these instructions: [Install MVS App for Camera Utilization](https://docs.openuc2.com/docs/Electronics/HIKCamera/SoftwareTutorial)

**Congratulations! You Have Completed All the Setup Steps! Now Let's Use the Microscope**

## Experiment 1: Bright Field Illumination

1. Turn the LED-matrix on and the blue LED off.
2. Insert the probe into the probe insert.
3. Start the camera by pressing the play button (▶).
4. Make sure your probe is centered. Shift it around until you see some structure on your screen.
5. The image you see might be blurry or, to be precise, out of focus. Use the PS4 controller to move the Z-stage up or down to get a sharp image.
6. Now you can move the probe around and inspect it properly.



## Experiment 2: Fluorescence Microscopy

1. To turn your microscope into a fluorescence microscope, turn the LED-matrix off and the blue LED on.
2. The probe should still be in the probe insert, and the camera should still be on.
3. At this point, you're likely seeing a black screen. This is because the fluorescence (the photons emitted by the probe) is much weaker than the bright LED-Array. To adjust, open the feature tree, go to `Acquisition Control`, and increase the `exposure time` to 300000ms. You should now see the fluorescence image.
Optional you can go to `Analog Control`, and increase the `Gain`.



## Experiment 3: Smart Microscopy Using ImSwitch and openUC2

For this, please refer to the installation instructions [here](https://docs.openuc2.com/docs/ImSwitch/Quickstart).

On top of this, you can use the following `ImSwitchClient` template to remote control your microscopy using google colab or jupyter notebook. This gives some hints on the use of the API:

<a target="_blank" href="https://colab.research.google.com/drive/1W3Jcw4gFn0jtQXa3_2aCtJYJglMNGkXr?usp=sharing">
  
</a>
This makes use of the default URL hosted publicly on https://imswitch.openuc2.com/imswitch/index.html, but you can change this to the `PORT` (i.e. 8001) and `URL` (e.g. the Raspberry Pi's IP address that runs ImSwitch in docker and is in the same network as you computer).

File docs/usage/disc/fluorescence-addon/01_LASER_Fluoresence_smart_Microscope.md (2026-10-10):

---
id: LASER_Fluoresence_microscope
title: openUC2 LASER Fluoresence microscope
---

#Tutorial: Building a Smart laser-Powered Fluorescence Microscope

In this workshop, we will guide you through assembling a laser-powered fluorescence microscope, allowing you to explore fascinating experiments with microscopic details.

### Materials Needed

1. laser diode
2. Beamsplitter
3. LED-Matrix with USB-C cable (for bright-field microscopy)
4. Electronic Z-stage with some technical nobs
5. Mainboard with UBC-mini cable
6. PS4 Controller (for controlling the Z-stage)
7. Infinity objective
8. biconvex lens (f'=50mm)
9. Camera with tube lens
10. Probe insert
11. Probes
12. cubes and base plates

### Diagram



### Theory of Operation

Fluorescence is a photophysical process that describes the spontaneous emission of light shortly after an electron is excited to a higher-energy state.
First, an electron is excited from the ground state to the higher-energy state  through absorption. After a short time (approximately 10⁻⁹ s), the excited electron returns to the ground state, releasing energy in the form of radiation. Due to the Stokes-shift within the S₁ state, the emitted light has a longer wavelength (λ₂) than the radiation used for excitation (λ₁).



### Theoretical Background: Fluorescence

Fluorescence is a photophysical process that describes the spontaneous emission of light shortly after an electron is excited to a higher-energy state.
First, an electron is excited from the ground state to the higher-energy state  through absorption. After a short time (approximately 10⁻⁹ s), the excited electron returns to the ground state, releasing energy in the form of radiation. Due to the Stokes-shift within the S₁ state, the emitted light has a longer wavelength (λ₂) than the radiation used for excitation (λ₁).



## Tutorial: LASER-Powered Fluorescence Microscope



### Step 1: Assemble the Microscope

This guide will walk you through building the microscope step by step. You can follow the assembly process according to the functional groups or refer to the diagram above.

#### 1.1: Assembling the Bright-Field Microscope

1. **Build the Baseplate**: This will connect the LED-matrix, probe insert, movable infinity objective, beamsplitter and the camera (which is already connected to the tube lens).Attach wo extra baseplates for the Z-stage.


2. **Attach the LED-matrix**: Place the LED-matrix and than the probe insert behind it, securing both with two baseplates on top.




3. **Install the movable Infinity-Objective**: Drill the objective into the objective mount of the electronic Z-stage. As you can see, there are two RMS-inserts for the Objective, how to choose the right one? In this assembly, because the Z-stage lays flat on the ground choose the insert thats closest to the Z-stage (50mm distance). As shown below the lettering "stage" is placed upward. The second option on the other side (55mm distance) you need when you built the microscope not flat laying, but standing on the ground. Why? Because then there will be an extra puzzle piece between the electronic z-stage and the objektive-mount, so to make shure the obejctive is still in fokus you need 5mm more distance to accomodate für the puzzle piece.
Lastly insert the technical pins on the long sides to attach the baseplates.


4. **Position the beamsplitter cube**: Insert the beamsplitter cube (you can leave it empty for now, it will be needed when assembling the fluorescence microscope).



5. **Add the camera**: Finally, attach the camera unit behind the beamsplitter and secure everything with a second layer of baseplates.





Now, your bright-field microscope is ready!

#### 1.2: Assembling the Fluorescence Microscope
But of course if you got this box you want more, so now let's start buidling the fluorescene Microscope

1. **Prepare a 4x1 Baseplate**: After that, attach it to the beamsplitter cube.

2. **Position the laser**: Place the laser at the furthest point from the beamsplitter.



3. **Collimate the Light**: The blue laser is a divergent light source because its a fiber laser, so use the f'=50mm biconvex lens to collimate the light.

5. **Focus the Light**: To focus the collimated light into the objective, insert an empty cube, followed by the f'=100mm biconvex lens.



6. **Insert the Beamsplitter**: Place the beamsplitter carefully. Make sure the filter sides are oriented correctly to avoid blocking the wrong wavelengths.





7. **Focus Light into the Infinity Objective**: to correctly focus the ligth into the infinity objective, position the biconvex lens and infinity objective with about 100mm of space between them.





After completing these steps, you're done with the assembly, nice job!

# Step 2: Turn Your Microscope Into a Smart One - aka the Electronics  

### 2.1: Plug in the Electronics as Shown Below

**⚠️ Caution!**
If you need to change any of the cables or their position, always unplug the 12V power cable before doing so. Otherwise, the electronic components might get damaged!

**⚠️**
These instructions based on the Pinlay-Out of the **ESO32-DEV-based UC2 standalone board V3 (beta)**)
find the Pin-layout for the **ESO32-DEV-based UC2 standalone board V4** [here](https://docs.openuc2.com/docs/Electronics/UC2StandaloneBoard/uc2e2v4)
- connect the LED-Matrix panel by plugging in the micro-USB and connect it to your PC.



- Connect the Z-stage to the `Z-Motor` on the main board. Ensure there's a motor driver.



- Connect the Laser to the Mainboard at `PMW1`and to `12V` Power:
  - the laser has two plugs: the one coming out of the big white cable goes to `12V` power supply
      - The **black** cable goes to `12V-GND`
  - the second plug goes to `PMW1`  
      - The **black** cable goes to `PMW1-GND`



- Plug in the micro-USB at your ESP32 and connect to your PC.

- Plug in the 12V power cable.



### 2.2: Flashing the ESP32 Firmware

1. Before proceeding, ensure your ESP32 board has the latest firmware. You can download and flash the firmware via the official [openUC2 website](https://youseetoo.github.io/), selecting **your version**, then click on the `connect` button. The source code can be found [here](https://github.com/youseetoo/uc2-esp32).

<p align="center">
<em>Flashing process shown for the ESP32-DEV-based UC2 standalone board V3 (beta).</em>
</p>



2. Connect the ESP32 to your computer using the micro-USB cable.  

3. In your Chrome browser, a dialog will prompt you to select the COM port for your ESP32, which should be shown as something similar to `CP2102 USB to UART Bridge Controller`. Once connected, you can install the latest firmware by simply clicking the "Install" button.
  

  

  If nothing shows up, you can install the drivers from the prompt that appears when you click anywhere on the screen:

   

4. Wait until the firmware has been successfully flashed.

5. &#x1F4A1; **flash your LED-matrix**. Repeat the same steps, but this time for the LED-matrix
   

### 2.3: Connecting to the Web Interface
 (valid since March 2025)

1. After flashing the firmware, go to the testing section on the same website.

2. Connect to your ESP32 board using the "Connect" button again, ensuring the correct COM port is selected.  

   

3. Once connected, test the system by sending a simple command:

```json
{"task":"/motor_act", "motor": { "steppers": [ { "stepperid": 3, "position": -1000, "speed": 1000, "isabs": 0} ] } }
```



This command will move the Z-axis motor by -1000 steps (1 full rotation) at a speed of 1000 steps per second. Each step corresponds to a movement of 300nm when using microstepping. You’ll observe the motor rotating, adjusting the focus.

**Note:** Ensure that the command string has no line breaks.

4. &#x1F4A1;**Connect your LED-matrix as well**. Duplicate the current tab and connect the LED-matrix again via the button. Choose the correct COM Port.  
Now you can test all components through these two tabs.

### 2.4: Testing in the Web Interface
(valid since March 2025)

1. After completing the test, go back to the first tab to control the other components via buttons:
   - `PMW1(on)` and `PMW1(off)` control the Laser.
   - `Motor Z(+)` and `Motor Z(-)` control the Z-stage.
   - `LED (on)` and `LED (off)` control the LED-matrix panel (&#x1F4A1;you must change tabs to control it).

### 2.5: Pairing the PS4 Controller &#x1F3AE;

The UC2-ESP firmware supports various input devices, including the PS4 controller, to make interacting with the microscope easier. While you've already worked with USB serial commands, using the PS4 controller offers a more flexible, hands-on approach. For more detailed instructions on pairing, refer to the [UC2 PS4 Controller Pairing Guide](https://docs.openuc2.com/docs/Electronics/PS4-Controller/PS4-Controller). Here’s a brief summary:

1. **Put your PS4 controller into pairing mode** by holding down the `Share` button and the `PS` button simultaneously until the light bar starts blinking.
2. Click the `Pair Controller` button in the web interface. Alternatively, open the serial prompt in your browser (connected to the ESP32 board) or use the web interface and enter the following command:

```json
{"task":"/bt_scan"}
```

  This will initiate the Bluetooth scan on the ESP32, which will detect and pair with the controller.

  Once paired, you can control the motorized stage using the analog sticks and switch the LED-matrix on/off using the buttons. The complete pinout of the diffrent function you can find here: [UC2 PS4 Controller Pairing Guide](https://docs.openuc2.com/docs/Electronics/PS4-Controller/PS4-Controller) (valid since June 2025)

### 2.6: Setup and Use the Camera Software
Instructions for the HIKROBOT - Camera - MV-CE060-10UM-PRO:

1. Connect the camera via cable to your PC.

2. For the installation process and useage of the software, follow these instructions: [Install MVS App for Camera Utilization](https://docs.openuc2.com/docs/Electronics/HIKCamera/SoftwareTutorial)

**Congratulations! You Have Completed All the Setup Steps! Now Let's Use the Microscope**

## Experiment 1: Bright Field Illumination

1. Turn the LED-matrix on and the blue LED off.
2. Insert the probe into the probe insert.
3. Start the camera by pressing the play button (▶).
4. Make sure your probe is centered. Shift it around until you see some structure on your screen.
5. The image you see might be blurry or, to be precise, out of focus. Use the PS4 controller to move the Z-stage up or down to get a sharp image.
6. Now you can move the probe around and inspect it properly.


Hellfeld-Bildaufnahme von Pollen

## Experiment 2: Fluorescence Microscopy

1. To turn your microscope into a fluorescence microscope, turn the LED-matrix off and the laser on.
2. The probe should still be in the probe insert, and the camera should still be on.
3. At this point, you're likely seeing a black screen. This is because the fluorescence (the photons emitted by the probe) is much weaker than the bright LED-Array. To adjust, open the feature tree in your camera programm, go to `Acquisition Control`, and increase the `Exposure time` to 300000 ms. You should now see the fluorescence image.
Optional you can go to `Analog Control`, and increase the `Gain`.


Fluoreszenz-Bildaufnahme von Lens-tissue-Fasern (mit fluoreszentem Marker präperiert)

## Experiment 3: Smart Microscopy Using ImSwitch and openUC2

For this, please refer to the installation instructions [here](https://docs.openuc2.com/docs/ImSwitch/Quickstart).

On top of this, you can use the following `ImSwitchClient` template to remote control your microscopy using google colab or jupyter notebook. This gives some hints on the use of the API:

<a target="_blank" href="https://colab.research.google.com/drive/1W3Jcw4gFn0jtQXa3_2aCtJYJglMNGkXr?usp=sharing">
  
</a>
This makes use of the default URL hosted publicly on https://imswitch.openuc2.com/imswitch/index.html, but you can change this to the `PORT` (i.e. 8001) nad `URL` (e.g. the Raspberry Pi's IP address that runs ImSwitch in docker and is in the same network as you computer).

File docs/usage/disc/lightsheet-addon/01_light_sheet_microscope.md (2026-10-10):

---
id: Light_sheet_Fluoresence_microscope
title: openUC2 light sheet fluoresence microscope
---

# Tutorial: Building a smart Light Sheet Fluorescence Microscope

In this workshop, we will guide you through assembling a light sheet fluorescence microscope. This technique enables fast, gentle, and high-contrast imaging of biological samples by illuminating only a thin slice of the specimen. By systematically shifting the sample in x, y, and z directions and stacking the resulting images, you can reconstruct detailed three-dimensional visualizations of microscopic structures.



### Materials Needed

1. Laser diode 488 nm
2. Biconvex lens f'=25 mm
3. Cylindrical lens f'=100 mm
4. Mirror
3. LED-Satellite-Matrix (enables bright-field microscopy for aligning)
4. Electronic Z-stage (for camera focus)
4. Electronic XYZ-Stage (for moving the Probe)
5. Mainboard with UBC-mini cable
6. PS4 Controller (for controlling the Z-stage)
7. Infinity objective 10x
8. Objective 4x with RMS Insert
8. Probe Chamber
8. Probes
9. Emission filter
9. Camera with tube lens
12. Cubes and base plates

### Diagram



### Theory of Operation

Light-sheet microscopy is based on the principle of fluorescence and like confocal microscopy, it is a technique that creates optical sections that can then be reconstructed into a coherent image. It differs from traditional microscopy technologies in its special type of illumination and detection, which enables gentler and faster acquisition of 3D images, making it particularly suitable for the three-dimensional visualization of biological samples.



To illuminate the sample, a thin light sheet is used, which is guided through the sample perpendicular to the optical axis of the detection optics. This enables layer-by-layer illumination within the depth of field ∆d of the objective, whereby only the focal plane of the sample is illuminated, while all other planes remain in darkness.

Initially, a slit created in various ways was used to generate the light sheet, but for biological fluorescently stained samples, it has now been switched to directing an expanded laser beam through a cylindrical lens.

The cylindrical lens has an effective cut in which it refracts the light rays like a centered lens in the meridional section (principal section) and focuses the light in a line (XY plane). In the YZ plane, however, it acts like a plane-parallel plate,
in which the geometry of the beam is preserved. This creates a light sheet,
where the height h corresponds to the diameter of the expanded laser beam.
The light sheet then strikes the sample to be examined and can be moved through it layer by layer (translation in the Y direction). It is aligned perpendicular to the optical axis of the detection optics, with the
light sheet being within the depth of field (d < ∆d) of the objective lens. This ensures that the recorded image contains no out-of-focus components. To ensure this even when moving in the Y direction through the sample, the position of the objective lens is continuously readjusted. Alternatively, instead of the light sheet, the sample itself can be shifted in the Y direction. In fluorescence microscopy, in particular, the red-shifted radiation emitted from the respective sample plane is detected. Using image processing software, the images of all layers can then be superimposed, creating a 3D image (3D stack) of the sample.

### Theoretical Background: Fluorescence

Fluorescence is a photophysical process that describes the spontaneous emission of light shortly after an electron is excited to a higher-energy state.
First, an electron is excited from the ground state to the higher-energy state  through absorption. After a short time (approximately 10⁻⁹ s), the excited electron returns to the ground state, releasing energy in the form of radiation. Due to the Stokes-shift within the S₁ state, the emitted light has a longer wavelength (λ₂) than the radiation used for excitation (λ₁).



## Tutorial: Light-sheet fluorescence microscope



## Step 1: Assemble the Microscope

This guide will walk you through the microscope assembly step by step. You can follow the process according to the functional modules or refer to the diagram above for orientation.

1. **Install the Laser Source**  
   Connect the fiber-coupled laser to the fiber coupler insert and securely fasten it.

2. **Insert the Collimating Lens**  
   To collimate the laser beam, insert a biconvex lens with a focal length of f' = 25 mm directly behind the fiber output, within the same optical cube.

   

   

3. **Leave Space for the Cylindrical Lens**  
   Do not insert the cylindrical lens yet. Leave physical space for it at the appropriate position. It will be inserted after initial beam alignment (see step 3).

   

4. **Place the 45° Mirror**  
   Insert a dielectric mirror at a 45° angle to redirect the beam around a corner, as needed for the optical path.
   

5. **Prepare and Mount the 4× Objective**  
   Disassemble the 4× objective lens as shown in the reference image. This modification allows the focal plane to be positioned close enough to the sample for proper alignment. Mount the modified objective onto the RMS insert.

   

6. **Position the sample aquarium chamber**  
   Place the sample aquarium chamber on the stage and fill it with water or your desired immersion medium.

   

   

7. **Add the LED Satellite Matrix (Optional)**  
     Position the LED matrix in the camera path. While not part of the core light-sheet setup, it is useful for illumination and alignment purposes in Step 3.

     

     

8. **Mount the electronic Z-stage**  
   Install the motorized Z-stage. Attach the **10× infinity-corrected objective** to the stage. This objective is used for imaging.

   

9. **Install the emission filter**  
   - If your emission filter is preassembled, proceed to the next step.  
   - Otherwise, locate the filter inside the **beamsplitter cube insert** from the FluoBox. It’s on the rear-facing side; the diagonal face holds the dichroic mirror.  Disassemble the beamsplitter to retrieve the emission filter and insert it into its designated mount. Secure it with the white retaining ring.

   

10. **Attach the Camera Module**  
   Align the camera unit and its corresponding **tube lens** directly behind the emission filter to ensure proper image formation.

   

   

11. **Leave Space for the XYZ Stage**  
    The XYZ stage is not required for initial alignment. You may leave it out during this step to increase working space and simplify alignment. Install it later, after completing optical alignment.

    

12. **Connect and Secure Components**  
    Use the puzzle connectors to link the modules.  
     **Important:** Make sure you don't put puzzle pieces on the cylindrical lens and mirror yet — leave them easily removable for adjustments during Step 3. Only secure all components once alignment is complete.

## Step 2: Electronics

**⚠️ ATTENTION!**

NEVER LOOK DIRECTLY INTO THE LASER! EYE WILL BE DAMAGED DIRECTLY

NEVER SWITCH ON THE LASER WITHOUT INTENDED USE

BEAM HAS TO GO AWAY FROM ONESELF - ALWAYS!

### 2.1: Plug in the Electronics as Shown Below

**⚠️ Caution!**
If you need to change any of the cables or their position, always unplug the 12V power cable before doing so. Otherwise, the electronic components might get damaged!

These instructions based on the Pinlay-Out of the **ESO32-DEV-based UC2 standalone board V3 (beta)**)
find the Pin-layout for the **ESO32-DEV-based UC2 standalone board V4** [here](https://docs.openuc2.com/docs/Electronics/UC2StandaloneBoard/uc2e2v4)


*Electronic without XYZ-Stage*

- connect the LED-Matrix to the Mainboard at `LED1`

- Connect the Z-stage to the position `Z-Motor` on the main board. Ensure there's a motor driver.

- Connect the 3 Motors of the XYZ-Stage to the respective positions `A-Motor`,  `X-Motor`,  `Y-Motor`. Ensure there are motor drivers as well.

- Connect the Laser to the Mainboard at `PMW1`and to `12V` Power:

- Plug in the micro-USB at your ESP32 and connect to your PC.

- Plug in the 12V power cable.

### 2.2: Flashing the ESP32 Firmware

1. Before proceeding, ensure your ESP32 board has the latest firmware. You can download and flash the firmware via the official [openUC2 website](https://youseetoo.github.io/), selecting **your version**, then click on the `connect` button. The source code can be found [here](https://github.com/youseetoo/uc2-esp32).

  <p align="center">
  <em>Flashing process shown for the ESP32-DEV-based UC2 standalone board V3 (beta).</em>
  </p>

  

2. Connect the ESP32 to your computer using the micro-USB cable.  

3. In your Chrome browser, a dialog will prompt you to select the COM port for your ESP32, which should be shown as `CP2102 USB to UART Bridge Controller`. Once connected, you can install the latest firmware by simply clicking the "Install" button.
  

  

  If nothing shows up, you can install the drivers from the prompt that appears when you click anywhere on the screen:

   

4. Wait until the firmware has been successfully flashed.

### 2.3: Connecting to the Web Interface
 (valid since March 2025)

1. After flashing the firmware, go to the testing section on the same website.

2. Connect to your ESP32 board using the "Connect" button again, ensuring the correct COM port is selected.  

   

3. Once connected, test the system by sending a simple command:

```json
{"task":"/motor_act", "motor": { "steppers": [ { "stepperid": 3, "position": -1000, "speed": 1000, "isabs": 0} ] } }
```



This command will move the Z-axis motor by -1000 steps (1 full rotation) at a speed of 1000 steps per second. Each step corresponds to a movement of 300nm when using microstepping. You’ll observe the motor rotating, adjusting the focus.

**Note:** Ensure that the command string has no line breaks.

### 2.4: Testing in the Web Interface
(valid since March 2025)

After completing the test, go back to the first tab to control the other components via buttons:

- `PM1(on)` and `PMW1(off)` control the laser.
- `Motor Z(+)` and `Motor Z(-)` control the Z-stage.
- `Motor X(+)/Y(+)/A(+)` and `Motor X(-)/Y(-)/A(-)` control the XYZ-stage.
- `LED (on)` and `LED (off)` control the LED-matrix panel,  as well as the other buttons in this section to turn on single LEDs or a ring pattern.

### 2.5: Pairing the PS4 Controller &#x1F3AE;

The UC2-ESP firmware supports various input devices, including the PS4 controller, to make interacting with the microscope easier. While you've already worked with USB serial commands, using the PS4 controller offers a more flexible, hands-on approach. For more detailed instructions on pairing, refer to the[UC2 PS4 Controller Pairing Guide](https://docs.openuc2.com/docs/Electronics/PS4-Controller/PS4-Controller). Here’s a brief summary:

1. **Put your PS4 controller into pairing mode** by holding down the `Share` button and the `PS` button simultaneously until the light bar starts blinking.
2. Click the `Pair Controller` button in the web interface. Alternatively, open the serial prompt in your browser (connected to the ESP32 board) or use the web interface and enter the following command:

```json
{"task":"/bt_scan"}
```

  This will initiate the Bluetooth scan on the ESP32, which will detect and pair with the controller.

  Once paired, you can control the motorized stage using the analog sticks and switch the LED-matrix on/off using the buttons. The complete pinout of the diffrent function you can find here: [UC2 PS4 Controller Pairing Guide](https://docs.openuc2.com/docs/Electronics/PS4-Controller/PS4-Controller)(valid since June 2025)

### 2.6: Setup and Use the Camera Software
Instructions for the HIKROBOT - Camera - MV-CE060-10UM-PRO:

1. Connect the camera via cable to your PC.

2. For the installation process and useage of the software, follow these instructions: [Install MVS App for Camera Utilization](https://docs.openuc2.com/docs/Electronics/HIKCamera/SoftwareTutorial)

## Step 3: Aligning the Microscope

Refer again to the alignment diagram that shows how the light sheet should intersect the detection path. The **focal point of the light sheet (its thinnest part)** must coincide precisely with the **optical axis of the detection optics**.

Following these steps carefully will ensure that the light sheet is centered within the field of view (FOV) and in focus with the detection objective. This alignment is crucial for obtaining high-resolution and reliable imaging results with the OpenUC2 light-sheet microscope.

👉 For additional tips and tricks, see:  
- [Light Sheet Sample Guide](https://docs.openuc2.com/docs/Toolboxes/LightsheetBox/LightSheet%20Sample/)  
- [Alignment video of an older light-sheet version](https://docs.openuc2.com/docs/Toolboxes/LightsheetBox/LightsheetCalibration)

---

1. **Collimate the Laser**  
   Remove the mirror temporarily and collimate the laser by adjusting the distance between the laser diode and the f' = 25 mm biconvex lens. The beam diameter should remain consistent regardless of viewing distance—this indicates good collimation.

   

   

2. **Insert the Mirror**  
   Guide the collimated beam into the 4× illumination objective by inserting the 45° mirror back into the microscope.

   

3. **Prepare the Probe Chamber**  
   Fill the chamber with water. To make the solution fluorescent, briefly dip the tip of a text marker into the water. This allows you to visualize the light sheet.
   Tonic Water or Bitter lemon would also work, but they tend to get sticky.

   

4. **Align the 4× Illumination Objective**  
   Turn on the laser and adjust the 4× objective so that the focus is on the optical axis of the detection path. The beam spot should appear as a small, focused dot.  For this it's easiest to use the camera:
     - Launch the software and **remove the emission filter**.
     - Turn on the **LED Satellite Matrix** to verify the camera is working (the screen should be bright white), then turn it off again.
     - Turn on the laser at full power.
     - Set the exposure time to **50,000–90,000 ms**, or higher if necessary.
     - You should now see a **sandglass-shaped beam**. Adjust the 4× objective to move the focal point (thinnest point) into the center.
     - Use the **Z-stage** to fine-tune the camera focus, making the beam waist as thin and sharp as possible.

     it should look something like this:
     

5. **Insert the Emission Filter**  
   Reinsert the emission filter. This will block the excitation light and allow only fluorescence to pass through to the camera. readjust the exposure time and the gain accordingly.

   

  Realign both the imaging and the dedection focus as needed. It then should look like this.

   

6. **Insert the Cylindrical Lens**  
      Insert the cylindrical lens to generate the light sheet. It should be positioned so that its focal plane aligns with the **back focal plane of the 4× objective (NA 0.1)**.  
      - For proper alignment, the **focal length of the cylindrical lens should match** the effective focal length of the 4× objective. Adjust until the sheet is as thin as possible (remove emission filter if needed).
      - After re-inserting the lens, recheck the alignment, as minor variations can occur during reassembly.

      > ℹ️ Once aligned, the cylindrical lens usually does not need to be recalibrated unless components are moved or replaced.
---
  7. **Final Check**

   - If alignment is correct and you **temporarily remove the emission filter**, you should see:
     - A fully illuminated camera image.
     - The light sheet filling the entire field of view.

     

   - If the light sheet appears **too high or too low** like this
   
   

    check:
     - Whether the **10× detection objective** is correctly positioned on the optical axis (e.g., loose screws can shift alignment).
     - Whether all modules and puzzle pieces are properly secured.

- You should now see **fluorescent particles** in the water as bright dots. Use the **Z-stage** to focus on the plane containing those particles.

- **Reinsert the Emission Filter**  
    You should now see a dark image with only **a few bright dots**. These are the particles in focus.

    

    Adjust exposure time and gain as necessary.

    

- **Last step**: Remove the fluorescent water and thoroughly clean the probe aquarium chamber.  
    - First, use a pipette to extract the water.  
    - Then, use lint-free tissue paper along with a pointed tool like tweezers or a small screwdriver to gently clean the chamber windows.  
  This step is **essential**, as fluorescent particles tend to stick to the glass surfaces, causing **unwanted scattering** in future experiments.

## Experiment 1: Imaging with the light-sheet microscope

1. insert a Probe into the Sample Holder of the XYZ-Stage, mount the XYZ-Stage to the Board and connect the motors.

  

  

  sample preparation: https://docs.openuc2.com/docs/Toolboxes/LightsheetBox/LightSheet%20Sample/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

2. insert clear water into the sample aqarium chamber

3. insert the XYZ-Stage on the board and connect the motors to the main board (see Step 2, don't forget to plug the 12V cable before doing so)

4. position the Probe in the light sheet.



5. adjust the acquisition time and gain accordingly

6. by moving the X and Y axis you position the probe
7. by moving the A axis you can "scroll" through your probe

  after you finished your experiemnts, don't forget to clean the sample chamber.

## Experiment 2: Generating Sacks Using ImSwitch (Rasperry Pi)

### Step 1: Installation process

For this, please refer to the installation instructions [here](https://docs.openuc2.com/docs/ImSwitch/Quickstart).

On top of this, you can use the following `ImSwitchClient` template to remote control your microscopy using google colab or jupyter notebook. This gives some hints on the use of the API:

<a target="_blank" href="https://colab.research.google.com/drive/1W3Jcw4gFn0jtQXa3_2aCtJYJglMNGkXr?usp=sharing">
  
</a>
This makes use of the default URL hosted publicly on https://imswitch.openuc2.com/imswitch/index.html, but you can change this to the `PORT` (i.e. 8001) nad `URL` (e.g. the Raspberry Pi's IP address that runs ImSwitch in docker and is in the same network as you computer).

### Step 2: Imaging and generating Stacks:
We assume the system is running and you were able to install ImSwitch on your computer. The configuration `JSON`file that describes the light-sheet system can be found further down this document. A tutorial on how to install our ImSwitch Version (SRC: https://github.com/openUC2/ImSwitch/) can be either found in the imSwitch repository or in the ImSwitch section in this wiki.

The Video below will show you how to run Imswitch and genereate data stacks.

<div style={{position: 'relative', paddingBottom: '56.25%', height: 0, overflow: 'hidden'}}>
  <iframe
    style={{position: 'absolute', top: 0, left: 0, width: '100%', height: '100%'}}
    src="https://www.youtube.com/embed/kr9_7XD-a4M?si=I0qcmhLNnKMY2EwI"
    title="YouTube video player"
    frameBorder="0"
    allow="accelerometer; autoplay; clipboard-write; encrypted-media; gyroscope; picture-in-picture"
    allowFullScreen
  />
</div>

## Brain imaging using dedicated Sample Adapter 

This is an SLA-printed chamber for Ethyl cinnemate with dentist glue to seal the chamber with the coverslips. 

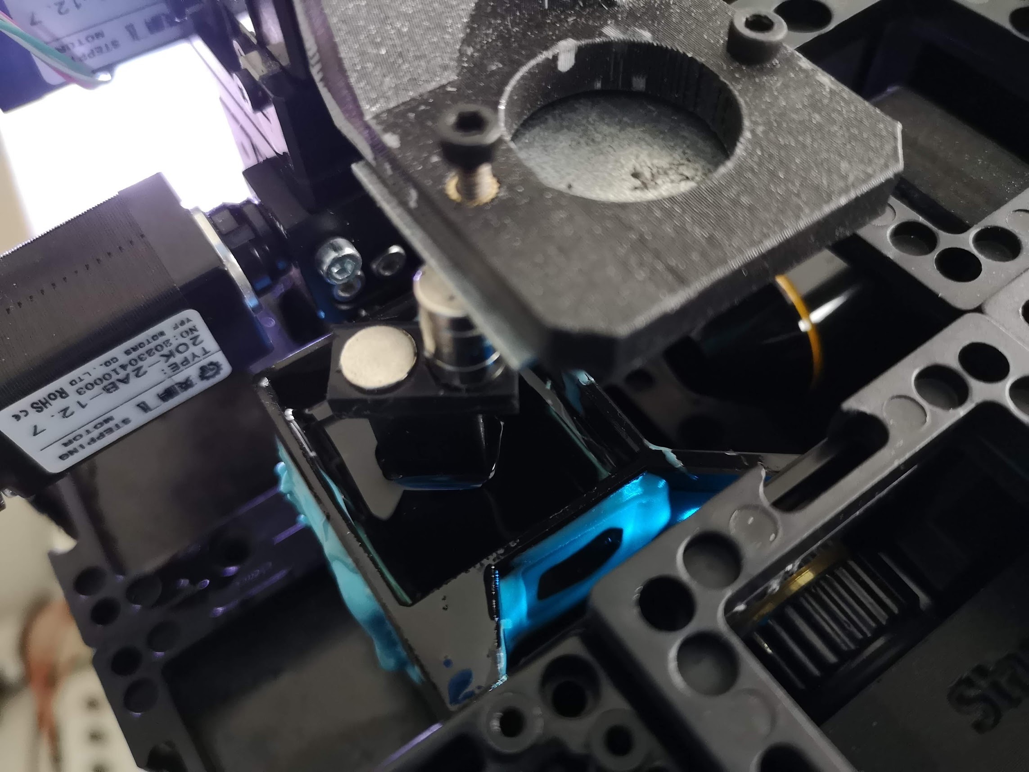
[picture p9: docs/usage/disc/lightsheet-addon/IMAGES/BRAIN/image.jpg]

*We use a magnetic plate on our xyz stage to mount the sample adapter to coarsly move it in xyz*

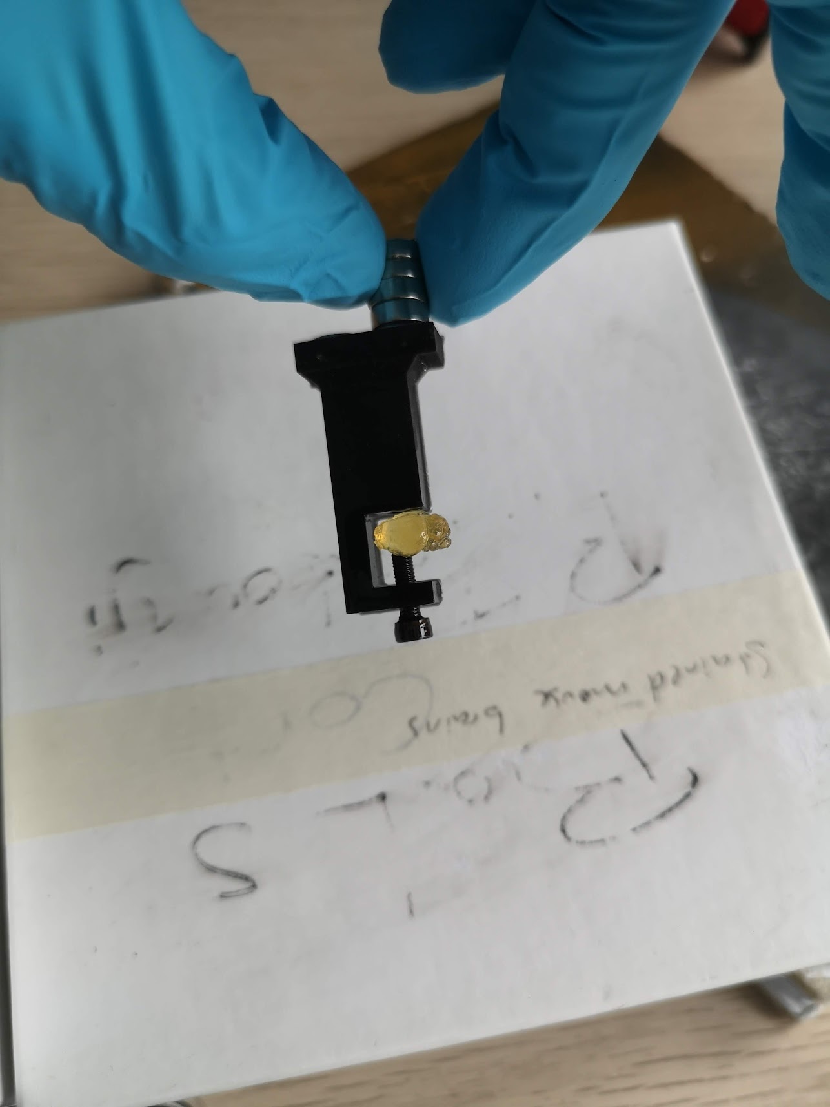
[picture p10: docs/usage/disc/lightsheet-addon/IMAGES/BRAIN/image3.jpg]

*This sla-printed adapter mounts to the xyz stage magnetically*

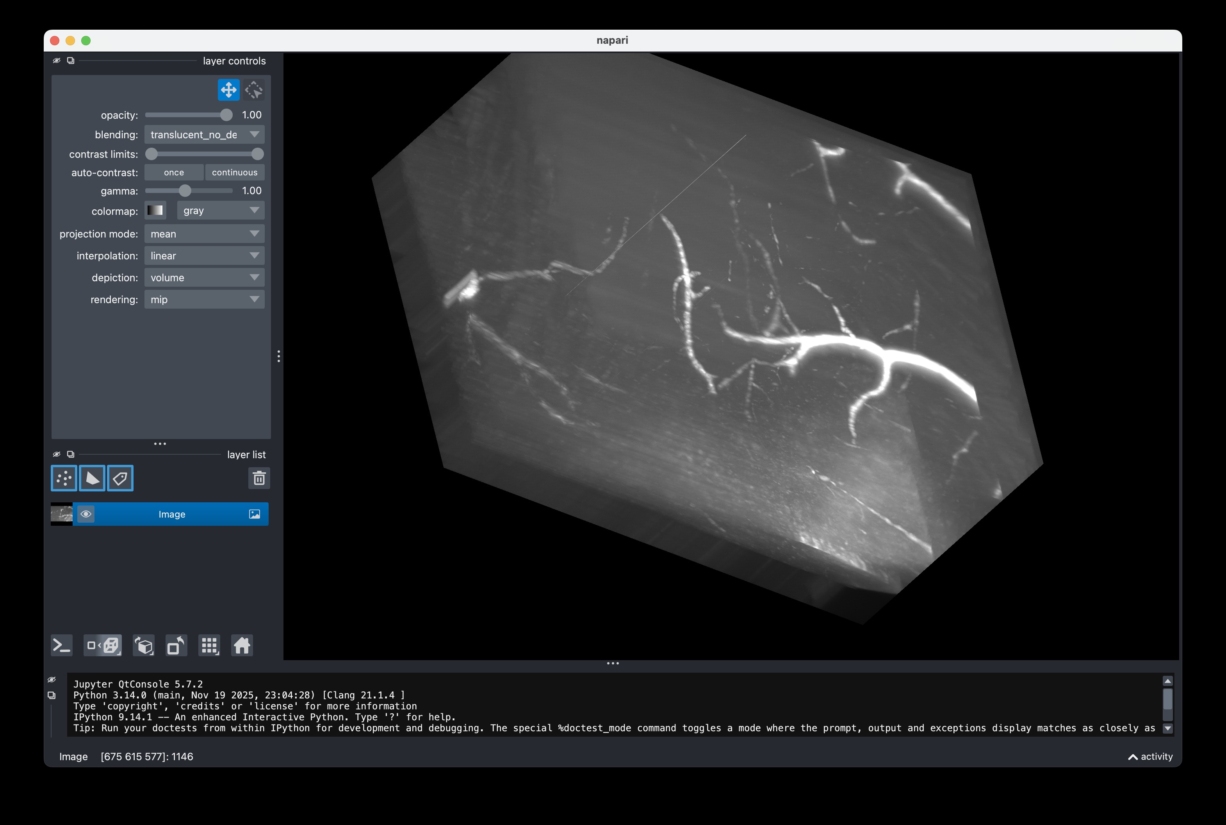
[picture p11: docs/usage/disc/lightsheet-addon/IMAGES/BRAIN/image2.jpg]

*This is a volume of (mostly autofluorescent) blood vessels and GFP-labelled neurons (I guess)*

### Stack of mouse brain images at 488nm 

The stripe artifacts come from the fact that we do not (yet) wiggle the single mode fiber or destroy coherence otherwise. On our Todo-List :)

<iframe width="560" height="315" src="https://www.youtube.com/embed/myeRIJ9bIFM?si=DjdAretNErPeKUl3" title="YouTube video player" frameborder="0" allow="accelerometer; autoplay; clipboard-write; encrypted-media; gyroscope; picture-in-picture; web-share" referrerpolicy="strict-origin-when-cross-origin" allowfullscreen></iframe>

### Walk-through Light-sheet imaging using ImSwitch

<iframe width="560" height="315" src="https://www.youtube.com/embed/W7HQ2r_jyn0?si=sQZ_DaPhPD1Ucn9Y" title="YouTube video player" frameborder="0" allow="accelerometer; autoplay; clipboard-write; encrypted-media; gyroscope; picture-in-picture; web-share" referrerpolicy="strict-origin-when-cross-origin" allowfullscreen></iframe>

<iframe width="560" height="315" src="https://www.youtube.com/embed/xjfJWYbQFIY?si=_jron7ZX2TIFEmxp" title="YouTube video player" frameborder="0" allow="accelerometer; autoplay; clipboard-write; encrypted-media; gyroscope; picture-in-picture; web-share" referrerpolicy="strict-origin-when-cross-origin" allowfullscreen></iframe>

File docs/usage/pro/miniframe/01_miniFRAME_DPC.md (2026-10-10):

# miniFRAME - DPC Module 

## 1. Concept and System Overview

openUC2 is widely known for its modular optical building blocks. Modern microscopy systems, however, go far beyond lenses and mirrors. Using cubes they can integrate opto-electronic, mechanical, and electro-mechanical components such as:

* Motorized axes (Z, XY, XYZ)
* LEDs and lasers
* Cameras and sensors
* Controllers and synchronization electronics
* ...or anything that fits ina cube essentially :-)

The challenge is not only connecting these components, but **coordinating them in time** by means of synchronized motion, scanning routines, long-term experiments, and automated workflows (in best case in a visually appealing UI).

We decided to put the  **Raspberry Pi** as the central hub to coordinate cameras, electronics, and software workflows to make software orchestration as reproducible as possible and to offload any installation issues to something that should always work. Together with an ESP32-based UC2 controller, it enables time-synchronized microscopy experiments via ImSwitch. 

## 2. Hardware Architecture

### 2.1 Core Components

* **Raspberry Pi** (central compute & networking node)
* **UC2 ESP32 Electronics** (low-level motion control, illumination, sensor input, feedback loops )
* **Cameras**

  * USB3 industrial cameras (e.g. HIK, Daheng)
  * Raspberry Pi CSI cameras (mostly used for the holography project)
* **Motor Drivers**

  * Typically TMC2209 or similar
  * Connected directly to ESP32 UC2 board
* **Illumination**

  * LED matrices (e.g. concentric ring illumination, Neopixel arrays)
  * Lasers (optional, safety-dependent, PWM driven)

The below diagram illustrates the overall architecture of the Raspberry Pi + ESP32 UC2 system. The Raspberry Pi connects to the ESP32 board and the camera via USB, while the ESP32 controls the stepper motors and LED illumination via direct connections and CAN-bus, respectively. The ESP32 UC2 board is powered by a 12 V power and powers the Raspberry Pi via a DC-DC converter (5V, 3A output).


*openUC2 Raspberry Pi + ESP32 system overview diagram*

## 3. Mini-FRAME / Inner Cube Hardware

The **Mini-FRAME (Inner Cube)** is the removable optical engine of the FRAME microscope. It can operate:

* **Standalone**, outside the large FRAME
* **Integrated**, sliding into the FRAME rail system

The following video explains the transition between both modes:

<iframe width="560" height="315" src="https://www.youtube.com/embed/41OIpK6xs8s?si=BA6UXgL7kI0CMD54" title="YouTube video player" frameborder="0" allow="accelerometer; autoplay; clipboard-write; encrypted-media; gyroscope; picture-in-picture; web-share" referrerpolicy="strict-origin-when-cross-origin" allowfullscreen></iframe>

### Key Properties

* Fully functional microscope core
* Modular UC2 cube construction
* Compatible with FRAME optics and mechanics
* Designed for rapid prototyping and method development
* Compact footprint: ~15 cm × 15 cm × 20 cm (L×W×H)
* small xyz stage for sample positioning

## 4. Mechanical and Optical Layout

This is an examplary layout of the inner cube stack of the miniFRAME system. Depending on your application you can modify the cubes and optics as you like. This only has a brightfield layer and a second layer for all the electronics. 


*The brightfield layer contains a folding mirror and a CCTV Lens as a tube lens, set to infinity. It produces an image on the camera sensor which is mounted in a UC2 camera cube. The rest is filled with cubes and puzzle pieces to arrive at a 3x3 layout. The camera here is a daheng industrial camera with a USB3 interface.*


*The upper layer contains the electronics mentioned ealier and is also filled with cubes and puzzle pieces to arrive at a 3x3 layout.*


*The entire inner cube is "sealed" with a top and bottom plate to provide stability and a good connection to the miniFRAME structure. The top plate also mountes puzzle pieces to for example add illumination arms. The xyz stage is mounted to the top plate as well permanently for stability.*


*The device in action*

### 4.1 Structure

* Upper and lower FRAME plates
* UC2 cube stack forming the optical axis
* Permanent XYZ or Z stage mounted to the top plate
* Electronics mounted underneath the top plate


*inner cube stack for sliding into the FRAME structure; the standalone version has additional puzzle pieces on the top plate to mount illumination arms and xyz stages*

Access to electronics is possible by removing the **four outer cross-head screws** holding the top plate.

 
*The bottom part has inserts that act like conter nuts to keep the screws in place. You can untighten them by loosening the screws from the top.*


*You can use a screwdriver to carefully lift the top plate off the cube stack once all screws are removed.*

The below video explains the assembly of the inner cube stack:

<iframe width="560" height="315" src="https://www.youtube.com/embed/aI-v6xWYpiM?si=qQRwuS0wDQwfkN00" title="YouTube video player" frameborder="0" allow="accelerometer; autoplay; clipboard-write; encrypted-media; gyroscope; picture-in-picture; web-share" referrerpolicy="strict-origin-when-cross-origin" allowfullscreen></iframe>

### 4.2 Optical Axis

* Coaxial with FRAME objective axis
* Objective mounted via **RMS adapter inside a UC2 cube**
* Objectives can be exchanged freely
* Sample mounted magnetically on the motorized stage

## 5. Electronics Integration

### 5.1 Controllers and Firmware

* **ESP32-based UC2 electronics**
* Firmware:

  * Standalone board v3: firmware `UC2_3` (USB serial only)
  * Standalone board v4: firmware `UC2_canopen_standalone_v4_release` (CAN master, node 1; motors on the board, LED matrix as CAN node 30; recommended)

Firmware names, node IDs and baud rates: [Boards, roles & node IDs](../../../dev/sw/interface/reference/boards-and-node-ids.md).

More information can be found in the [UC2 Electronics Add-On Documentation](../../disc/electronics-addon/01_Quickstart.md).

Stepper motors are connected directly to the standalone board, typically using **TMC2209 drivers**. Ensure the motor current for the NEMA 11 motor is set to approximately **800 mA** (adjustable via potentiometer on the driver board). Typically this is on the far right position when turning clockwise.

### 5.2 Illumination

* LED matrix with **three concentric rings**
* CAN-bus controlled
* Enables DPC, brightfield, oblique illumination


*The DPCController App in ImSwitch enables differential phase contrast imaging by synchronizing the LED illumination with the camera acquisition. It can help you acquire sequence of images with different illumination patterns automatically and aim to reconstruct the images using DPC algorithms from Laura Waller et al.*


*The DPC illumination sequence cycles through left, right, top, and bottom LED rings to enable differential phase contrast imaging.*

### 5.4 DPC Imaging

We have created a walk-through video how you can acquire DPC images with the miniFRAME system using ImSwitch and then reconstruct it using a Jupyter notebook that runs our open-source DPC reconstruction code inspired from Laura Waller et al.

<iframe width="560" height="315" src="https://www.youtube.com/embed/G51u3CgQ8Ng?si=9V3zftmnia1tUjQM" title="YouTube video player" frameborder="0" allow="accelerometer; autoplay; clipboard-write; encrypted-media; gyroscope; picture-in-picture; web-share" referrerpolicy="strict-origin-when-cross-origin" allowfullscreen></iframe>

The result does not look as expected since the sample wasn't really thin (wellplate) and we see quiet a lot of shadows. However, the idea of the gradient becomes visible. You can tune the thykonov regularization parameter to get smoother results. 



You can find the Jupyter notebook [here](https://github.com/openUC2/imswitchclient/blob/main/examples/ImSwitch_DPC.ipynb). 

It runs on ImSwitch with 
```json
"availableWidgets": [
    "DPC", 
    "LedMatrix
  ]
```

We use the new CAN-Bus controlled LED Matrix. But it will work with the small UC2-LED equally (8x8) well. 

### FPM Imaging  

This is an image series acquired with multiple LEDs turned sequentially. This can be used to perfrom Fourier Ptychographic Microscopy (FPM) as well.



## 6. Camera Integration

* USB-C industrial camera mounted inside a UC2 cube (Daheng or HIK, more information in the [Camera Documentation](../../components/hik-camera/README.md))
* Optical coupling via **100mm CCTV optics** or Tube lens into an infinity-corrected path - we aim for Nyquist sampling at the sensor
* Enables widefield and computational imaging modes

You can revisite the setup in the [OpenUC2 Configurator](https://youseetoo.github.io/configurator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)



## 7. Setting Up the miniFRAME System

### Required Connections

* 12 V power supply → UC2 electronics power input
* USB (USB-C or Micro-USB) → Raspberry Pi ↔ ESP32
* USB3 camera cable → Raspberry Pi (blue USB port)
* CAN cable (JST connector) → LED matrix
* Optional Ethernet cable → Raspberry Pi

### First Power-Up Checklist

* All UC2 cubes mechanically secured
* Camera connected to USB3 port
* ESP32 connected via USB
* Power supply connected
* Optional Ethernet connected

After power-up, the system automatically starts and exposes a WiFi network.

### Step-by-Step Setting up the miniFRAME including the Software Onboarding 


*Component Overview: Illumination arm (LED array), inner cube stack with xyz stage, Joystick, USB cable for ESP and camera, Power supply*


*Add the CAN-bus wire to the LED ring (JST connector)*


*Add he USB Cable to the USB3 camera*


*Connect the other end of the camera cable to the blue USB3 port of the Raspberry Pi*


*Connect the USB cable from the ESP32 UC2 board to the Raspberry Pi (USB-C or Micro-USB)*


*Add the USB cable to the non-blue USB port of the Raspberry Pi (for network and power)*


*Add the Illumination Arm to the Mini-FRAME structure by placing it on the puzzle pieces*


*Add the 12V power supply to the power input*


*Press the power button on the Raspberry Pi to start the system*


*The system will start and expose a WiFi network named openUC2-XXXX-XXXX; You can connect to it using the password `youseetoo`*


*You can now access the ImSwitch web interface by opening a browser and navigating to http://openuc2.local or http://192.168.4.1 to access the admin panel and the ImSwitch instance*

## 9. Wireless Access

* SSID: `openUC2-XXXX-XXXX`
* Password: `youseetoo`

The name is derived lexicographically from the Raspberry Pi MAC address and is globally unique.

## 10. Recommended First Tests

* Connect via WiFi
* Open the web interface (see software guide, `http://openuc2.local` or `http://192.168.4.1`)
* Test:

  * Live camera feed
  * Z movement
  * LED ring switching
  * Joystick or web-based stage control

# Troubleshooting

## Raspberry PI + ESP32 UC2 Electronics


*Wiring of the Raspberry Pi and ESP32 UC2 electronics for the miniFRAME system: The power button is soldered to the power pins of the Raspberry Pi 5. The 5V for the Pi is coming from the DC-DC converter on the ESP32 UC2 board. The USB cable connects the ESP32 UC2 board to the Raspberry Pi for communication. It has to deliver enough power to drive the pi. For this short wires and larger diameter are working best.*


*Everything is mounted int he case to to follow the UC2 standard. The ESP32 UC2 board is mounted upside down to have access to the stepper motor connectors and the power input.*


*Puzzle Pieces are mounted on the bottom part of the electronics component to connect it to the miniFRAME structure.*


*This is the entire module where the ESP32 is driving the stepper motors of the xyz stage and controlling the LED illumination via CAN-bus and the Raspberry Pi is connected via USB for communication and control. ImSwitch is running on the Pi to provide the user interface and orchestrate the entire system.*

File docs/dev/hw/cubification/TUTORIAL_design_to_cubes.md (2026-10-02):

# From an optical design to openUC2 cubes: a short tutorial

This is an example how you can go from an arbitrary optical sketch/design/layout into something cube-based. We have decided to use the open-source OpenRAMAN spectrometer since this is not strictly 50mm/rectangular design to demonstrate that the cubes can also deal with this.

How to take an optical design that exists as a Zemax or Optiland file and build it in the openUC2 cube system. The worked example is the OpenRAMAN spectrometer (https://docs.open-raman.org, Luc Boussemaere, CC BY-SA 4.0) on the quantum‑kit base plate. Every number below is produced by the scripts in this repository (https://github.com/openUC2/openuc2-openraman).

In general, you have to follow the following steps (instead of Zemax, you can also use an optiland file of course since we convert it into optiland):
The seven steps

## What you need

- The design as a file with real distances. Here: `reference/P00006 - OPTICAL PATH.zmx`. (or optiland)
- The outer shape of every bought part: lenses, filters, mounts, laser, camera (STEP files or data
  sheets).
- The facts about the cube system (step 3). They are constants in `raman_layout.py`.
- Python with Optiland and CadQuery (commands at the end).

## 1. Read the design and rebuild it

*This part is very specific and was claude generated. Other ZMX files need different treatment, but follow the same principle. We will work on a way to automate this step in the upcoming Optikit*

`raman_zmx.py` reads the Zemax text file, follows its coordinate breaks and returns every element
with its position and direction: 57 surfaces become objective, dichroic, edge filter, window,
focusing lens, slit, collimator, grating and camera lens.

`raman_optics.py` builds the same system in Optiland and compares it with the file: 29 checks
(distances, focal lengths, the grating equation, 16.67 nm/mm dispersion, the slit image). Later
steps change distances; this model is what tells you whether a change is harmless.

Two things were not in the file and came from the OpenRAMAN CAD: the laser path (the laser runs
50 mm beside the main axis) and the camera lens (a black box in the file, modelled as an ideal
50 mm lens).

## 2. Sort the distances: locked or free

Which distances may change

Change one air gap by ± 1 mm, trace again, look at the spot at the next focus.

- **Locked (3):** sample → objective, focusing lens → slit, slit → collimator. One millimetre
  takes the spot on the slit from 17 µm to 41–76 µm. These distances stay as in the file.
- **Free (6):** everything in a collimated beam: objective → dichroic → edge filter → window →
  focusing lens, collimator → grating, grating → camera lens. The spot does not change, even for
  + 60 mm.

Optics joined by a locked distance move together as one block: sample with objective; focusing
lens with slit and collimator. Tilted plates keep their angles; only their positions are free.

This test was done for the point the laser illuminates, on the axis. A design that images a wide
field needs the same test at the edge of the field: a longer collimated gap moves the beam
sideways on the next lens.

## 3. Know what a cube can hold

Section of a cube along the beam

| fact | value |
| --- | --- |
| cell pitch of the quantum‑kit base plates | 50.1 mm (not 50.0) |
| cube | 49.8 mm |
| notches for inserts along the beam | −15 … +15 mm in 5 mm steps |
| inserts with the full outline | within ± 17 mm of the cube centre (the end frames start at 17.2 mm) |
| round printed part, radius up to 19.2 mm | within ± 18.6 mm |
| beyond ± 21 mm, up to the face | only parts thinner than 34 mm (a laser nose, a lens tube) |
| master insert (moulded, PRT‑2100 and PRT‑2123) | 4 mm thick |
| joint planes of a sandwich of two master inserts | ± 2, ± 3, ± 7, ± 8, ± 12, ± 13 mm |
| optic centre to joint plane | up to 4 mm |
| window of a cube face between the corner posts | 34 mm |

The consequence that decides most layouts: at every cube boundary 16 mm of the beam path are
closed for holders (from + 17 mm in one cube to − 17 mm in the next).

## 4. Folds on cube centres, then move optics inside free gaps

**Folds first.** The point where the beam axis meets a 90° mirror or dichroic goes on a cube
centre. Both beams then leave through the centres of cube faces. For OpenRAMAN the dichroic's
coated face sits on the centre of cube (1, 0). The steering mirror is then one cube up and the
laser one cube further; the file's 50 mm between laser axis and main axis becomes 50.1 mm, which
is a free distance.

**Then walk along the axis.** Each optic falls into a cube at some distance from the cube
centre. With the distances of the file, two holders do not fit: the objective's would end at
+ 21.1 mm and the window's at + 27.1 mm, both past the 18.6 mm limit.

The main axis before and after the fit

**Move only what is free, and as little as possible.** An optic with a free gap on both sides
goes to the nearest joint plane that fits. A block moves as a whole. `fit_to_grid.py` tries the
candidates and lets the checks of `raman_layout.py` decide:

| distance (mm) | Zemax file | search | built in round 1 (by hand) |
| --- | --- | --- | --- |
| objective → dichroic | 30.0 | 34.1 | 34.0 |
| dichroic → edge filter | 48.2 | 41.4 | 40.4 |
| edge filter → window | 18.5 | 14.4 | 14.4 |
| dichroic → focusing lens | 86.7 | 86.7 | 86.7 |
| the three locked distances | 15.58, 15.58, 43.22 | unchanged | unchanged |

The search and the hand layout differ by 0.1 mm at the objective and by 1 mm in the filter cube
(filter and window at − 7 / + 8 mm instead of − 8 / + 7 mm). Both pass the layout checks, and
the holders of both generate. The Inventor assembly and the checks of step 7 exist only for the
hand layout. The full comparison is in `layouts/fit_report.md`.

**Check the optics again** with the new distances: 20 of 20 for both (`fit_to_grid.py` runs the
checks on its result, `raman_optics.py --validate --cube` on the hand layout).

## 5. What cannot go into a cube goes on a plate

Corner posts and the arm on a plate

A beam that starts on a cube centre gets out only near the four grid directions: up to 34° from a
face normal for a thin beam, 18° for the 16.9 mm beam behind the collimator. The grating sends
the light back at 47.5° to the main axis, so the grating, the camera lens and the camera cannot
be in cubes.

They stand on a solid plate in the puzzle layer (5 mm thick). The plate replaces the puzzle pieces
under the arm and uses their M3 holes in the base plate. It carries a pedestal for the grating's
kinematic mount, a saddle for the lens barrel and a cradle for the camera (three M3 screws from
below).

The two free distances of the arm are set by clearances, not by the grid: the diffracted beam has
to pass the corner of the last cube (collimator → grating 55 mm instead of 50 mm), and the lens
barrel has to clear that cube.

Decide early how much goes on the plate. Layout A keeps the collimator in a cube. Layout B puts
it on the plate too: slit to camera then sit on fewer separate parts, and the grating can move
20 mm closer.

## 6. Pick a holder for every element

Which holder for which element

The two routes inside a cube:

- **Master inserts.** Two moulded inserts carry a small round printed part on the cube's notch
  grid. Use it for round optics up to 36 mm that the beam only passes through, at any tilt, and
  for thin cylinders. Several fit in one cube.
- **Square insert.** One printed insert with the full outline. Use it when the beam also leaves
  sideways (a 90° fold), when the part is not round (vial, cuvette, beamsplitter cube), or when
  an existing kinematic insert has to carry the optic.

For OpenRAMAN: six cartridges, one round clamp (laser), one square insert (sample), one existing
kinematic mirror cube, one printed frame in the existing kinematic splitter insert (dichroic), one
printed adapter in a kinematic mount (grating), one plate.

## 7. Generate, assemble, check

One file drives the rest: `layouts/<variant>/raman_layout.json` holds every frame, cube,
cartridge and placement.

- `raman_holders.py` writes a STEP file for every printed part.
- `raman_beam_solids.py` writes the beams as solids.
- `build_raman_assembly.py` builds the Inventor assembly from the placements.
- `check_raman_assembly.py` tests the built assembly: every optic lies in the pocket cut for it,
  no holder overlaps another part by more than 0.12 mm, the beams pass at the design aperture and
  at the aperture limit.

When a check fails, change a distance in step 4 and generate again. Do not repair a generated
part by hand. In round 1 the overlap test found three errors that the layout in the plane had
passed: the objective's sandwich with its joint at + 17 mm inside the end frame, the window
cartridge reaching into the end frame, and the sample insert with its outline turned by 90°.

## 8. What has to stay adjustable

| what | why | how |
| --- | --- | --- |
| focus at the sample and at the slit | 0.1 mm doubles the spot; a printed cartridge holds a lens with 0.15 mm of play | shims or a fine thread at objective and slit (open) |
| laser onto the collection axis | two beams through one objective | two kinematic mounts: steering mirror and dichroic |
| grating angle | 24 nm per degree | kinematic mount |
| camera focus | the slit image has to be sharp on the sensor | focus ring of the camera lens |
| slit rotation | the slit image has to follow the pixel columns | turn the slit disc in its cartridge before clamping (open) |

## 9. The result

Layout A from above

| layout | cubes | cells of the plate | collimator → grating | beyond the base plate |
| --- | --- | --- | --- | --- |
| A, collimator in a cube | 7 | 5 | 55 mm | grating mount 24.7 mm |
| B, collimator on the plate | 6 | 7 | 35 mm | grating mount 8.4 mm |
| C, as B on the 5 × 4 plate | 6 | 7 | 35 mm | the sample cube stands on an outrigger |

All three use 6 × 3 cells (300.6 × 150.3 mm), the size of the OpenRAMAN base plate.
Layout B: [img/layout_B.svg](img/layout_B.svg).

## Things that cost time

- **Distances in the file are not always paraxial.** OpenRAMAN's working distances are 0.175 mm
  and 0.249 mm inside the paraxial foci: best focus at full aperture. Keep the file's numbers.
- **The pitch is 50.1 mm.** Over six cubes that is 0.5 mm, more than the focus tolerance.
- **Vendor CAD has its own frames.** Measure where the optical surface is in each file before
  placing it (table in `RAMAN_PROJECT_PLAN.md`, section 7).
- **Insert springs overlap the cube by design** (about 0.3 mm near the legs). An overlap check
  has to leave that zone out.
- **Mount knobs need a hand.** The dichroic's kinematic mount hangs over the plate edge on
  purpose.

How this procedure runs without a person in the loop, and what the optikit editor needs for it:
`optikit-core/DOCS/roadmap/PLAN-EMBED-OPTICAL-DESIGN.md`.

*The optical design is OpenRAMAN's (CC BY‑SA 4.0). This tutorial and the derived layouts carry
the same licence and attribution.*

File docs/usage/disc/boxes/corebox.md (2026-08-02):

openUC2 GmbH
Search...
All Products
Discovery | CoreBox
Discovery | CoreBox
Discovery | CoreBox
Discovery | CoreBox
CORE BOX
CORE BOX
CORE BOX
Discovery | CoreBox
openUC2 CoreBox

Discover Geometrical Optics Hands-On

Unlock the fascinating world of geometrical optics with the openUC2 CoreBox, a comprehensive modular kit that enables you to explore, experiment, and understand the fundamental principles of lenses, mirrors, and optical systems. Whether you're a beginner or an enthusiast, this kit is designed to make optics accessible and engaging. Download our wonderful experiment guide here: 

 OpenUC2 - CoreBox Experiments.pdf

Included Components
Cube Modules

2x 45° Mirror (fixed, front surface)
2x 50mm Lens
1x 100mm Lens
1x -50mm Lens
1x Eyepiece
1x Universal Smartphone Carrier
1x Sample Mount
1x Z-stage (25mm travel)
Additional Accessories

10x Puzzle Base-Plates
2x Sample in 1x Sample-Box
Sample Preparation Kit
1x M3 Screw driver
1x Objective Lens (4x, NA = 0.1, finite)
1x Torch
Lens Cloth
QR Code (for documentation and tutorials)
What You'll Learn
Begin with the basics: learn how to find the focal length of a simple lens and understand the foundational concepts of optics. Progress through increasingly complex setups to build and analyze optical systems:

Telescopes: Understand magnification and field of view.
Microscopes: Create your first microscope and explore finite vs. infinite-corrected setups.
Digital Integration: Use your smartphone to capture and analyze data.
This kit is the foundation for all other openUC2 modules, giving you ample components to experiment, tinker, and build your own optical systems.

Get Started with Optics Today

Take your first steps into the world of light and lenses with the openUC2 CoreBox. It's not just a kit—it's a gateway to innovation and discovery.

Learn More

399.00 € VAT Excluded
1
Documents
 OpenUC2 - CoreBox Experiments.pdf
Terms and Conditions
Shipping: on stock, within 2 weeks! 

Why Choose the openUC2 CoreBox?
Fully modular and easy-to-use components
Open-source design with detailed online documentation
Perfect for workshops, classrooms, and personal projects
Expandable with additional kits to explore advanced topics like fluorescence and interferometry

Useful Links
Home
About us
Products
Privacy Conditions
Terms & Conditions 
Contact us
Cancellation policy
Imprint
About us
We are a team of passionate people whose goal is to improve everyone's life through disruptive products. We build great products to solve your business problems.

Our products are designed for small to medium size companies willing to optimize their performance.

Connect with us
hello@openuc2.com
Contact us

Copyright © 2022 - 2026 OpenUC2 GmbH. All Rights reserved.
Cookie Policy

Powered by Odoo - The #1 Open Source eCommerce

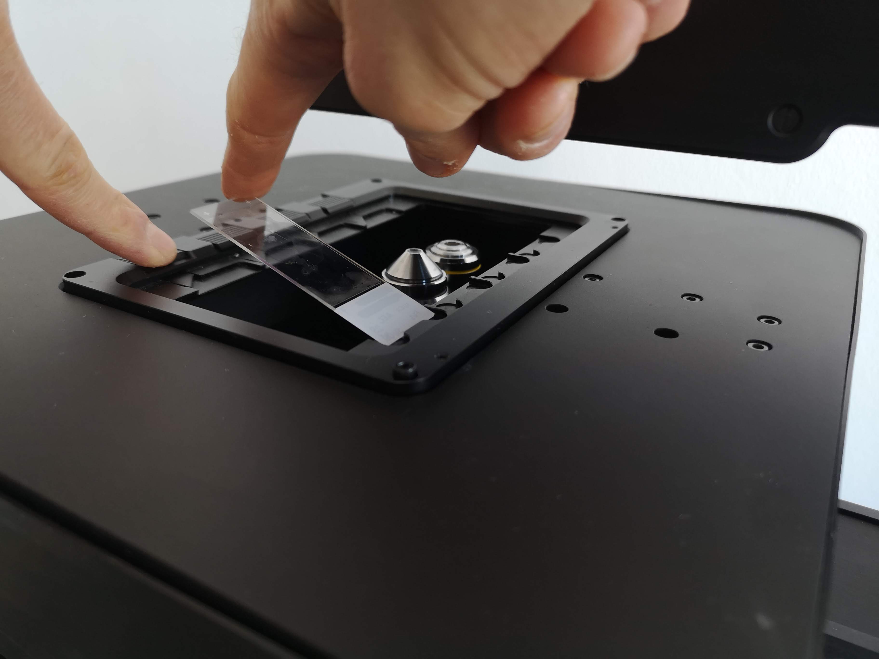
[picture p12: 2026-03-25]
docs/usage/pro/frame/tutorials/day-1/first-sample/slide-holder-insert-pull-spring.jpg

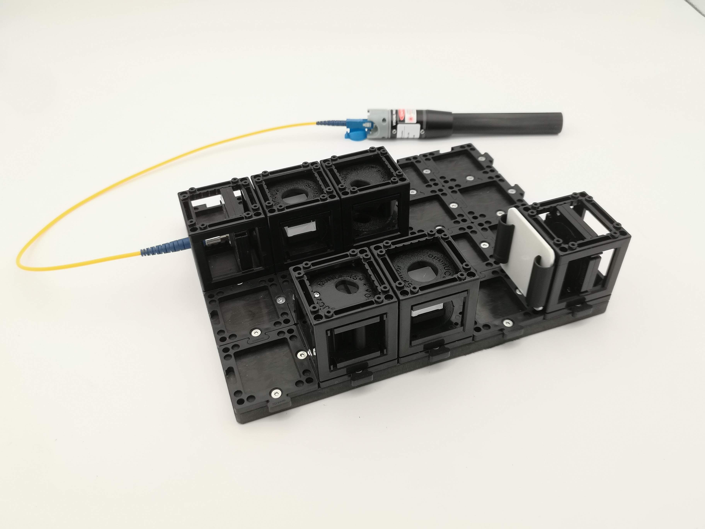
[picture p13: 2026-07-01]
docs/usage/disc/holobox/how-to/IMG_20260626_075948.jpg

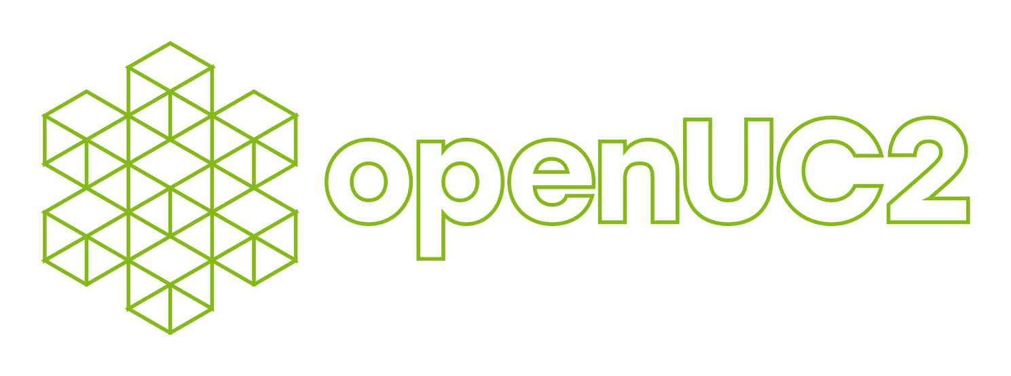
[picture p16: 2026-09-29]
docs/dev/design/brand-guidelines/images/incorrect-4-outline.png

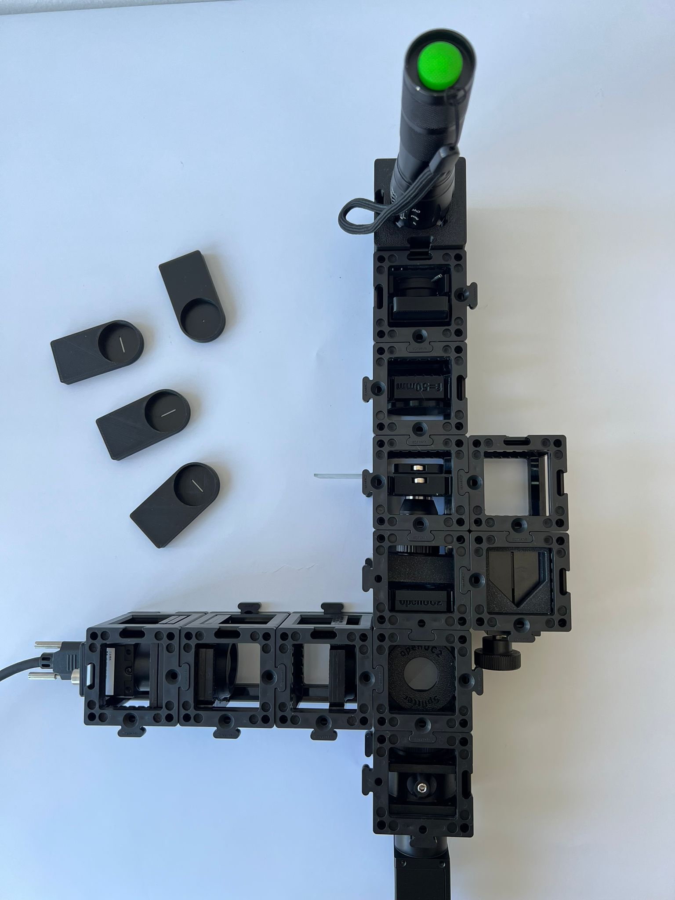
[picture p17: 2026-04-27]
docs/usage/disc/infinity-addon/IMAGES/ABBE_3.jpeg

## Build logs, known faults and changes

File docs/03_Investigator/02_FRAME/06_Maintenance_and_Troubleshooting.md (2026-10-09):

# Maintenance and Troubleshooting

## Preventive Maintenance Schedule

### Daily Maintenance Tasks

#### System Inspection (5 minutes)
- [ ] Visual inspection for loose components
- [ ] Check stage movement smoothness
- [ ] Verify illumination system operation
- [ ] Ensure workspace is clean and organized

#### Basic Cleaning
- [ ] Clean sample holders and stage surface
- [ ] Remove dust from external surfaces
- [ ] Check for cable damage or wear
- [ ] Verify all connections are secure

### Weekly Maintenance Tasks

#### Optical System Maintenance (15 minutes)

1. **Objective Lens Cleaning**:
   ```
   ⚠️ CAUTION: Use only appropriate cleaning materials to avoid damage.
   ```
   - Power off system before cleaning
   - Use lens cleaning paper and solution
   - Clean with gentle circular motions from center outward
   - Allow to air dry completely
   - Inspect for scratches or damage

2. **Condenser Cleaning**:
   - Remove condenser assembly if necessary
   - Clean all optical surfaces
   - Check aperture diaphragm operation
   - Verify centering adjustments

3. **Mirror and Prism Cleaning**:
   - Use appropriate cleaning solutions
   - Avoid touching first-surface mirrors
   - Check alignment after cleaning
   - Document any adjustments made

4. **Inner Cube System Maintenance**:
   ```
   ⚠️ CAUTION: Power off system completely before cube manipulation.
   ```
   - Remove each cube individually for inspection
   - Clean cube interfaces and optical surfaces
   - Check drawer rail alignment and smooth operation
   - Verify cube locking mechanisms function properly
   - Test cube installation/removal procedures
   - Document cube positions and configurations

#### Mechanical System Maintenance (20 minutes)

1. **Stage System**:
   - Clean stage rails and guides
   - Check for wear or damage
   - Lubricate moving parts (if specified)
   - Verify position accuracy with test sample

2. **Focus Mechanism**:
   - Check focus tension adjustment
   - Verify smooth operation throughout range
   - Clean focus scales and indicators
   - Test emergency stop functionality

3. **Frame and Mounting**:
   - Check all mounting screws for tightness
   - Verify system level and stability
   - Inspect vibration isolation
   - Clean and organize cable management

### Monthly Maintenance Tasks

#### Electronic System Maintenance (30 minutes)

1. **Control Electronics**:
   - Check cooling fans for dust buildup
   - Verify all LED indicators are functioning
   - Test communication interfaces
   - Update firmware if available

2. **Motor Systems** (Motorized versions):
   - Check motor coupling alignment
   - Verify encoder operation
   - Test limit switches
   - Check cable routing and protection

3. **Power Systems**:
   - Verify voltage levels at test points
   - Check fuse condition and ratings
   - Inspect power cables for damage
   - Test ground connections

#### Software Maintenance (15 minutes)

1. **Software Updates**:
   - Check for ImSwitch updates
   - Update device drivers
   - Backup configuration files
   - Test all software functions

2. **Data Management**:
   - Archive old image files
   - Clean temporary files
   - Backup calibration data
   - Update user documentation

#### Motor Controller Firmware Updates

```
⚠️ CAUTION: Firmware updates should only be performed when necessary.
```

The motor controllers may occasionally require firmware updates. Each axis controller can be updated individually, either over the CAN bus through the HAT+ without opening the box ([Update firmware over CAN](../../dev/sw/interface/how-to/update-firmware-over-can.md)) or by USB as shown below:


*The firmware of the motor controllers may change (hopefully not at all), but if needed, individual motor firmware can be updated. The axes are labeled on the outer box (X,Y,Z,A). Connect a USB-C cable to the appropriate controller.*


*Open the page youseetoo.github.io and select the motor driver as the firmware source. If initial flashing doesn't work, erase the firmware first using https://espressif.github.io/esptool-js/ then retry the update process.*

**Update Procedure**:
1. Identify the axis requiring update (X, Y, Z, A labels on controllers)
2. Connect USB-C cable to specific motor controller
3. Access firmware update website: youseetoo.github.io
4. Select appropriate motor driver firmware
5. If update fails, erase existing firmware using ESP tool
6. Retry firmware installation
7. Test motor functionality after update
8. Document firmware version and date

### Quarterly Maintenance Tasks

#### Comprehensive System Check (60 minutes)

1. **Precision Testing**:
   - Stage positioning accuracy test
   - Focus repeatability test
   - Image quality assessment
   - Illumination uniformity check

2. **Environmental Monitoring**:
   - Temperature sensor calibration
   - Humidity sensor verification
   - Vibration analysis
   - EMI testing (if applicable)

3. **Safety System Verification**:
   - Emergency stop testing
   - Interlock system verification
   - UV safety system check
   - Electrical safety inspection

## Cleaning Procedures

### Optical Component Cleaning

#### Materials Required
- Lens cleaning paper (lint-free)
- Optical cleaning solution (isopropanol-based)
- Cotton swabs (optical grade)
- Compressed air (oil-free)
- Anti-static cleaning cloth

#### Cleaning Solutions

**Approved Cleaning Solutions**:
- Isopropanol (99% pure)
- Commercial lens cleaning solutions
- Distilled water (for water-soluble residues)

**Prohibited Materials**:
- Paper towels or tissues
- Acetone or aggressive solvents
- Abrasive cleaners
- Household cleaning products

#### Step-by-Step Cleaning Process

1. **Preparation**:
   ```
   ⚠️ WARNING: Power off system and allow cooling before cleaning.
   ```
   - Turn off all power
   - Allow system to reach room temperature
   - Gather appropriate cleaning materials
   - Work in clean, dust-free environment

2. **Dust Removal**:
   - Use compressed air to remove loose particles
   - Work from center to edges
   - Use low pressure to avoid damage
   - Never touch optical surfaces directly

3. **Cleaning Solution Application**:
   - Apply small amount of solution to cleaning paper
   - Use gentle circular motions from center outward
   - Work in overlapping spirals
   - Avoid excessive pressure

4. **Drying and Inspection**:
   - Allow natural air drying
   - Inspect under good lighting
   - Repeat if necessary
   - Document any damage found

#### Optics Cube Removal and Deep Cleaning

```
⚠️ CAUTION: Follow proper procedure to avoid damaging optical components.
```

When deeper cleaning or optical alignment is required, the inner optics cube can be removed:

1. **Preparation**:
   - Power down the system completely
   - Allow system to cool to room temperature


*Disconnect the USB3 cable from the camera before removing the optics cube.*

2. **Removal Process**:


*Unscrew the securing capped screws that fix the optics cube in the FRAME.*


*Pull out the entire optics assembly. There is a linear rail that helps you move it in/out precisely.*

3. **Safe Storage and Cleaning**:


*Make sure you store the cube safely somewhere. In this configuration you can clean the optics with compressed air and perform detailed optical maintenance.*

4. **Reinstallation**:
   - Reverse the removal procedure
   - Ensure proper alignment with linear rail
   - Reconnect all cables securely
   - Test system functionality after reassembly

### Mechanical Component Maintenance

#### Stage System Cleaning

1. **Stage Rails**:
   - Remove accumulated debris
   - Clean with appropriate solvent
   - Check for wear or scoring
   - Apply specified lubricant if needed

2. **Sample Holders**:
   - Remove biological residues
   - Clean with mild detergent
   - Rinse with distilled water
   - Dry completely before use

#### Focus Mechanism Maintenance

1. **Focus Scales**:
   - Clean graduations with soft brush
   - Remove any built-up debris
   - Check scale accuracy
   - Verify pointer alignment

2. **Adjustment Knobs**:
   - Clean grip surfaces
   - Check for smooth operation
   - Verify tension adjustments
   - Test throughout full range

## Calibration Procedures

### Stage Calibration

#### Position Accuracy Calibration

1. **Equipment Required**:
   - Calibrated stage micrometer
   - High-resolution camera
   - Stable lighting
   - Calibration software

2. **Procedure**:
   ```
   📝 NOTE: Perform calibration at operating temperature.
   ```
   - Install stage micrometer
   - Home all axes
   - Measure known distances
   - Calculate scaling factors
   - Update software parameters

3. **Acceptance Criteria**:
   - X-axis accuracy: ±2 μm over 50 mm
   - Y-axis accuracy: ±2 μm over 75 mm
   - Repeatability: ±0.5 μm

#### Angular Calibration

1. **Equipment Required**:
   - Precision angle standard
   - Rotary stage (if applicable)
   - Angular measurement software

2. **Procedure**:
   - Mount angle standard
   - Measure known angles
   - Check linearity
   - Update calibration tables

### Focus System Calibration

#### Manual Focus Calibration

1. **Scale Verification**:
   - Use precision gauge blocks
   - Measure focus travel
   - Check scale linearity
   - Adjust scale if necessary

2. **Repeatability Test**:
   - Return to reference position multiple times
   - Measure deviation
   - Document results
   - Adjust if outside specifications

#### Motorized Focus Calibration

1. **Encoder Calibration**:
   - Home focus system
   - Move to known positions
   - Verify encoder counts
   - Update position tables

2. **Backlash Compensation**:
   - Measure backlash in both directions
   - Set software compensation
   - Verify improvement
   - Document settings

### Camera System Calibration

#### Pixel Size Calibration

1. **Equipment Required**:
   - Calibrated micrometer slide
   - Stable illumination
   - Image analysis software

2. **Procedure**:
   - Capture image of micrometer
   - Measure pixel distance between graduations
   - Calculate pixels per micrometer
   - Update software settings

3. **Verification**:
   - Measure multiple distances
   - Check consistency
   - Document calibration factor
   - Verify at different magnifications

#### Camera Linearity

1. **Intensity Linearity**:
   - Use calibrated neutral density filters
   - Measure response at different intensities
   - Check for linearity
   - Document response curve

2. **Geometric Distortion**:
   - Image grid pattern
   - Measure distortion across field
   - Generate correction map
   - Apply in software

## Troubleshooting Guide

### Systematic Troubleshooting Approach

#### Problem Identification

1. **Symptom Documentation**:
   - Describe problem precisely
   - Note when problem occurs
   - Document error messages
   - Record environmental conditions

2. **Problem Categorization**:
   - Mechanical issues
   - Optical problems
   - Electronic failures
   - Software errors

#### Diagnostic Tools

1. **Hardware Diagnostics**:
   - Built-in system diagnostics
   - External test equipment
   - Calibration standards
   - Measurement devices

2. **Software Diagnostics**:
   - System log files
   - Error reporting tools
   - Performance monitors
   - Network diagnostics

### Common Problems and Solutions

#### Mechanical Issues

**Problem: Stage Movement Issues**

*Symptoms*: Jerky movement, positioning errors, binding

*Diagnostic Steps*:
1. Check for debris on rails
2. Verify motor connections
3. Test limit switches
4. Check encoder operation

*Solutions*:
- Clean stage rails and guides
- Adjust motor driver current
- Replace damaged cables
- Realign mechanical components

**Problem: Focus Drift**

*Symptoms*: Image slowly goes out of focus

*Diagnostic Steps*:
1. Monitor temperature stability
2. Check mechanical connections
3. Verify objective mounting
4. Test focus repeatability

*Solutions*:
- Allow longer warm-up time
- Tighten mounting screws
- Improve environmental control
- Replace worn components

#### Optical Issues

**Problem: Poor Image Quality**

*Symptoms*: Blurry images, low contrast, artifacts

*Diagnostic Steps*:
1. Check objective cleanliness
2. Verify illumination alignment
3. Test with known good sample
4. Check camera focus

*Solutions*:
- Clean optical components
- Realign illumination system
- Adjust condenser settings
- Recalibrate camera focus

**Problem: Uneven Illumination**

*Symptoms*: Bright or dark areas in image

*Diagnostic Steps*:
1. Check LED alignment
2. Verify condenser position
3. Test with different samples
4. Measure illumination profile

*Solutions*:
- Realign LED system
- Adjust condenser height
- Clean condenser lens
- Replace faulty LEDs

#### Electronic Problems

**Problem: Communication Errors**

*Symptoms*: Device not responding, timeout errors

*Diagnostic Steps*:
1. Check cable connections
2. Verify device addresses
3. Test communication protocol
4. Check network settings

*Solutions*:
- Reseat cables
- Reconfigure device addresses
- Update drivers
- Reset network settings

**Problem: Motor Control Issues**

*Symptoms*: Motors not moving, erratic movement

*Diagnostic Steps*:
1. Check motor power supply
2. Verify driver settings
3. Test motor cables
4. Check control signals

*Solutions*:
- Replace power supply
- Adjust driver parameters
- Replace damaged cables
- Reset motor controllers

#### Software Problems

**Problem: Software Crashes**

*Symptoms*: Application stops responding, error dialogs

*Diagnostic Steps*:
1. Check system resources
2. Review error logs
3. Test with minimal configuration
4. Verify software version

*Solutions*:
- Close other applications
- Update software
- Increase virtual memory
- Reinstall problematic modules

**Problem: Image Acquisition Failures**

*Symptoms*: No images captured, corrupted files

*Diagnostic Steps*:
1. Check camera connection
2. Verify disk space
3. Test camera settings
4. Check file permissions

*Solutions*:
- Reinstall camera drivers
- Free disk space
- Reset camera parameters
- Modify file permissions

## Service and Support

### When to Contact Service

#### Immediate Service Required

Contact service immediately for:
- Safety system failures
- Electrical hazards
- Mechanical damage
- Laser safety violations (if applicable)

#### Scheduled Service Recommended

Contact service for:
- Annual calibration verification
- Major component upgrades
- Performance outside specifications
- Persistent unexplained problems

### Service Preparation

#### Information to Gather

Before contacting service:
- System serial number
- Software version numbers
- Problem description
- Error messages or codes
- Recent changes to system

#### System Documentation

Prepare for service visit:
- System configuration files
- Calibration records
- Maintenance logs
- User manual and documentation

### Warranty Information

#### Warranty Coverage

Standard warranty includes:
- 1 year parts and labor
- Software updates
- Technical support
- Calibration verification

#### Warranty Limitations

Warranty void if:
- System modified without authorization
- Operated outside specifications
- Damaged by misuse
- Serviced by unauthorized personnel

### Technical Support

#### Contact Information

**Technical Support**:
- Email: support@openuc2.com
- Phone: +49 (0) XXXX XXXXXX
- Hours: 9:00 AM - 5:00 PM CET, Monday-Friday

**Emergency Support**:
- Available 24/7 for safety-related issues
- Contact through main support number

#### Online Resources

- User manual downloads
- Software updates
- FAQ database
- Video tutorials
- Community forums

### Spare Parts and Consumables

#### Common Spare Parts

| Part | Part Number | Recommended Quantity |
|---|---|---|
| Fuses (5A, slow blow) | F001-5A | 5 pieces |
| LED modules | LED-001 | 2 pieces |
| Cable assemblies | CAB-001 | 1 set |
| Optical cleaning kit | CLEAN-001 | 1 kit |

#### Consumables

| Item | Part Number | Replacement Interval |
|---|---|---|
| Lens cleaning paper | PAPER-001 | As needed |
| Cleaning solution | CLEAN-002 | 6 months |
| Compressed air | AIR-001 | As needed |
| Fuses | Various | As needed |

#### Ordering Information

- Parts available through openUC2 or authorized distributors
- Minimum order quantities may apply
- Express shipping available for critical parts
- Bulk discounts available for educational institutions

*Continue to [Appendix](./07_Appendix.md) for additional reference information.*

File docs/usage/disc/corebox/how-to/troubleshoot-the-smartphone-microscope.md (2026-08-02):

---
title: Troubleshoot the smartphone microscope
sidebar_position: 7
description: Stripes, glare, dark corners, low contrast — every common bad image, its cause, and the two-minute fix.
---

# How to troubleshoot the smartphone microscope

*Task-oriented. Match your bad image to the pictures below; each has a one-line
cause and fix.*

This is what you're aiming for — a fully working setup and a clean image:


*The reference setup.*


*The reference image: even illumination, good contrast, sharp across the field.*

## Stripes across the image



**Cause:** the torch is in a blinking/PWM mode; its flicker beats against the
phone's rolling shutter.
**Fix:** press the torch button repeatedly until you reach the **brightest,
constant** mode.


*The torch has several modes — you want steady maximum, not strobe/morse.*

## One bright hotspot, dark surroundings



**Cause:** the torch's front lens is focused too tightly.
**Fix:** the torch head **slides to refocus** — adjust it until the sample is lit
evenly. (Bonus physics: when the LED is imaged into the condenser's focus you've
built Köhler-style illumination.)

## Everything washed out / overexposed



**Cause:** too much light.
**Fix:** put a paper diffuser between torch and sample, tap the phone screen to
lock exposure on the sample, or use half-empty batteries. A diffuser also smooths
the illumination:


*With diffuser: lower contrast, but pleasantly even.*

## Image only fills a small circle / dark vignette



**Cause:** the phone camera is too far from the eyepiece — the exit pupil of the
eyepiece must land on the camera's entrance pupil.
**Fix:** lower the phone until it (almost) touches the eyepiece, and centre it until
the full circle lights up.


*Match the eyepiece exit pupil to the camera pupil.*

## Shadows / relief instead of even brightness



**Cause:** the torch is off-axis; light hits the sample at an angle.
**Fix:** re-centre the torch above the condenser — *or keep it*: oblique
illumination adds contrast to transparent samples and is a legitimate technique.


*Oblique illumination geometry.*

Push it to the extreme (no direct light reaches the objective) and you get
**darkfield**: bright structures on a black background.


*Darkfield with the CoreBox: very oblique light only.*

## Still stuck?

Work down this list in order:

1. **Sample centred** over the objective? (Most common issue by far.)
2. **Focus range:** turn the Z-stage gear through its whole travel slowly; the focal
   plane of the 4× objective is thin.
3. **Everything on one axis?** Objective, mirrors, eyepiece, camera — one tilted
   insert breaks the chain: [Open and reconfigure a cube](./open-and-reconfigure-a-cube.md).
4. **Phone HDR/auto-enhance off** for scientific images — it invents detail.

## Related

- [Your first microscope](../tutorials/your-first-microscope.md)
- [Prepare your own sample](./prepare-your-own-sample.md)

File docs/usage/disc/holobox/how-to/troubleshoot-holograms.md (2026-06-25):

---
title: Troubleshoot holograms
sidebar_position: 3
description: Fix the common problems that stop an inline hologram from reconstructing cleanly — organised by what you're seeing.
---

# How to troubleshoot a hologram

*Task-oriented. Find your symptom, apply the fix.*

Inline holography is simple to build but fussy to get right. Almost every failure comes
down to one of four things: **coherence, stray light, geometry, or reconstruction
settings.** Find your symptom below.

## Symptom: no rings or fringes at all on the live image

The hologram pattern never forms. Work through these in order:

1. **Too much stray light.** This is the #1 cause. Cover the whole setup with a box or dark
   cloth so only the LED reaches the sensor. Contrast should jump immediately.
2. **Pinhole too big.** A large pinhole kills spatial coherence. Make a fresh, **smaller**
   one (fold foil ~8×, punch, pick the tiniest clean hole).
3. **Sample too far from the sensor.** It must be **almost touching** the sensor. Even a
   few millimetres of gap can wash out the pattern.
4. **Sample too dense.** A crowded or thick sample scatters everything into mush. Switch to
   a **sparse** sample — a little dust, pollen, or a few isolated particles.
5. **No colour filter.** Without it the LED is too broadband (low temporal coherence). Add
   the gel filter.

:::tip Prove the optics work first
Remove the sample entirely and look at the bare illumination. You should see smooth, even
light. If *that's* messy or full of stray glare, fix the light source and shielding before
worrying about samples.
:::

## Symptom: the reconstruction never comes into focus

You see rings, but dragging `dz` never produces a sharp image.

- **Wavelength is wrong.** Set it to match your filter — green ≈ 532 nm, blue ≈ 450 nm, red
  ≈ 650 nm. A wrong wavelength shifts where focus lands and degrades it.
- **Pixel size is wrong.** For the Raspberry Pi camera the default is **3.45 µm**. If you
  changed cameras or binning, update it. (See
  [Parts and parameters](../glossary/parts-and-parameters.md).)
- **You're not scanning `dz` far enough.** Sweep slowly across the **whole** range; the
  focus distance can be larger than you expect. Then fine-tune around the best spot.
- **Wrong colour channel.** Read the channel that matches your filter (red filter → red
  channel). The wrong channel can be nearly blank.

## Symptom: a ghostly halo around the sample

That's the **twin image**, and it is **normal** for simple inline holography — not a fault.
It happens because the camera records only brightness and loses the wave's phase, so the
real image and its mirror twin both focus at once. ([Full explanation.](../explanation/what-is-a-hologram.md#the-catch-the-twin-image))

For a first hologram, just recognise it and move on. To reduce it you'd need advanced
phase-retrieval algorithms or an **off-axis** setup (the
[Mach–Zehnder](./build-a-mach-zehnder.md) route).

## Symptom: blocky, smeared, or "JPEG-looking" reconstruction

- **Compression artifacts.** Capture at the **highest resolution and least compression**
  the camera offers. Heavy JPEG compression bakes in blocks that the reconstruction then
  amplifies.
- Save stills in a **lossless** format (PNG) rather than JPEG when reconstructing offline.

## Symptom: the pattern shifts, swims, or won't hold still

Mechanical instability.

- Put everything on a **solid, heavy surface.** No wobbly desks.
- Make sure every cube is locked on puzzle pieces top and bottom.
- Shield from **draughts**, and don't lean on or bump the table while capturing.
- Let the setup **settle** for a few seconds after any adjustment before judging it.

## Quick reference table

| You see… | Most likely cause | First thing to try |
|---|---|---|
| No fringes at all | Stray light | Cover the setup |
| No fringes at all | Pinhole too big | Make a smaller pinhole |
| Faint / mushy fringes | Sample too dense or too far | Sparser sample, move it onto the sensor |
| Won't focus | Wrong wavelength / pixel size | Match settings to hardware |
| Won't focus | `dz` range too small | Sweep the full distance range |
| Halo around sample | Twin image (normal) | Accept it, or go off-axis |
| Blocky image | JPEG compression | Capture lossless, max resolution |
| Pattern swimming | Vibration / draught | Stabilise and shield the setup |

## Related

- [Your first hologram](../tutorials/your-first-hologram.md) — the full build.
- [Parts and parameters](../glossary/parts-and-parameters.md) — every setting and its
  default.
- [How reconstruction works](../explanation/how-reconstruction-works.md) — why these
  settings matter.

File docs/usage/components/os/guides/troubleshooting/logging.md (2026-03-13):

---
toc_max_heading_level: 4
---

# Logging

## System logs

### How to enable persistent logging

If your machine is an RPi running openUC2 OS, then to make journald store logs persistently across boots you should:

1. Shut down the machine.
2. Remove the RPi's SD card and insert it into your own computer instead.
3. Mount the SD card's root partition on your computer.
4. Make a new directory in the SD card's root partition at `/etc/systemd/journald.conf.d`.
5. In the new directory at `/etc/systemd/journald.conf.d`, make a new file named `99-persistent-storage.conf`, with the following contents:
   ```ini
   [Journal]
   Storage=persistent
   ```
6. Reboot

:::warning

Storing logs persistently will wear out the SD card more quickly, so only do this if necessary!

:::

To undo this change:

1. Shut down the RPi.
2. Remove the RPi's SD card and insert it into your own computer instead.
3. Mount the SD card's root partition on your computer.
4. Delete the file at `/etc/systemd/journald.conf.d/99-persistent-storage.conf`.
5. Reboot

### How to check logs from a previous boot

After [enabling persistent logging](#how-to-enable-persistent-logging):

1. [Enter the machine's terminal](../day-1/access.md#the-machines-terminal).
2. Run the command `journalctl --boot=-{n}` to check the logs from `n` boots ago.
   For example, run `journalctl --boot=-1` to check the logs from the previous boot.

## Firmware communication logs

### How to enable the serial monitor tool

To install and enable our developer tool for viewing serial communication messages between the machine and all attached microcontrollers:

1. [Connect the machine to the internet](../day-1/connectivity.md#how-to-connect-the-machine-to-the-internet).
2. Run `forklift pallet enable-depl --apply dev/serial-monitor`.

To undo this change:

1. Run `forklift pallet disable-depl --apply --cache-img=false dev/serial-monitor`

### How to monitor serial communication messages

After [enabling the serial monitor tool](#how-to-enable-the-serial-monitor-tool):

1. [Open the machine's landing page](../day-1/connectivity.md#how-to-access-the-machines-landing-page).
2. Add `/dev/serial-monitor` to the landing page's URL in your web browser's address bar, and open the resulting URL.
   For example, if you access the landing page at [http://openuc2.local](http://openuc2.local), then you should open [http://openuc2.local/dev/serial-monitor](http://openuc2.local/dev/serial-monitor)
3. ??? (TODO: add instructions for how to use the serial monitor tool!)

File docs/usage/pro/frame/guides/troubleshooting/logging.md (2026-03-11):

---
toc_max_heading_level: 4
---

# Logging

## System logs

### How to enable persistent logging

To make journald store logs persistently across boots:

1. Shut down the RPi.
2. Remove the RPi's SD card and insert it into your own computer instead.
3. Mount the SD card's root partition on your computer.
4. Make a new directory in the SD card's root partition at `/etc/systemd/journald.conf.d`.
5. In the new directory at `/etc/systemd/journald.conf.d`, make a new file named `99-persistent-storage.conf`, with the following contents:
   ```ini
   [Journal]
   Storage=persistent
   ```
6. Reboot

:::warning

Storing logs persistently will wear out the SD card more quickly, so only do this if necessary!

:::

To undo this change:

1. Shut down the RPi.
2. Remove the RPi's SD card and insert it into your own computer instead.
3. Mount the SD card's root partition on your computer.
4. Delete the file at `/etc/systemd/journald.conf.d/99-persistent-storage.conf`.
5. Reboot

### How to check logs from a previous boot

After [enabling persistent logging](#how-to-enable-persistent-logging):

1. [Enter the RPi's terminal](../day-1/sw-access/README.md#the-frames-terminal).
2. Run the command `journalctl --boot=-{n}` to check the logs from `n` boots ago.
   For example, run `journalctl --boot=-1` to check the logs from the previous boot.

## Firmware communication logs

### How to enable the serial monitor tool

To install and enable our developer tool for viewing serial communication messages between the RPi and the microcontrollers:

1. [Connect the FRAME to the internet](../day-1/connectivity/README.md#how-to-connect-the-frame-to-the-internet).
2. Run `forklift pallet enable-depl --apply dev/serial-monitor`.

To undo this change:

1. Run `forklift pallet disable-depl --apply --cache-img=false dev/serial-monitor`

### How to monitor serial communication messages

After [enabling the serial monitor tool](#how-to-enable-the-serial-monitor-tool):

1. [Open the FRAME's landing page](../day-1/connectivity/README.md#how-to-access-the-frames-landing-page).
2. Add `/dev/serial-monitor` to the landing page's URL in your web browser's address bar, and open the resulting URL.
   For example, if you access the landing page at [http://openuc2.local](http://openuc2.local), then you should open [http://openuc2.local/dev/serial-monitor](http://openuc2.local/dev/serial-monitor)
3. ??? (TODO: add instructions for how to use the serial monitor tool!)

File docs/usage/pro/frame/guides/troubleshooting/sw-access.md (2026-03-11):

---
toc_max_heading_level: 4
---

# Software Access

The how-to guides here will help you to determine why you can't access a particular software program which is supposed to be running in openUC2 OS.

## How to troubleshoot an inaccessible network service

1. If the network service is deployed as a Docker container, [check the status of its Docker container(s)](#how-to-check-docker-container-status).

   Otherwise, if the network service is deployed as a systemd service, [check the status of its systemd service(s)](#how-to-check-systemd-service-status).

3. If the network service is supposed to be accessed via port 80, 443, or 8000, check whether other network services (e.g. ImSwitch, the openUC2 offline documentation, and the system file manager) are available over those ports by [opening their browser apps](../day-1/sw-access/README.md#browser-apps).

4. If the network service binds directly to a port on the RPi, [check the network port bindings](#how-to-check-network-port-bindings) to determine whether the network service is bound to its expected port.

   If not the network service is not bound to its expected port, check whether some other network service is already bound to the network port.

5. Check whether the network service is accessible over a local connection from within the RPi (i.e. as `localhost`).

6. [Check the firewall settings](#how-to-check-firewall-settings) on the RPi to determine whether the firewall is configured to make the network service (and any network ports which it binds to) accessible over external network connections.

   If not, [open the port in the firewall](#how-to-open-a-new-firewall-port).
   If opening the firewall port doesn't seem to help, then check whether [disabling the firewall](#how-to-disable-the-firewall) makes the port accessible.
   If the port becomes accessible after disabling the firewall, then you have not correctly opened the port in the firewall.

## How to check Docker container status

### via Dozzle

1. [Open the browser app](../day-1/sw-access/README.md#browser-apps) for Dozzle.
2. If the Docker container does not appear in the sidebar's list of running containers, then either the container has stopped or it never started.
   In that case, open the settings menu in the sidebar; if the "Show All Containers" menu item doesn't show a checked checkbox to indicate that it's enabled, click on that menu item to make Dozzle show all containers. If the Docker container then appears with a red circle, then the container has stopped.
3. Click on the container in the sidebar to see its logs.

### via the terminal

1. [Enter the RPi's terminal](../day-1/sw-access/README.md#the-frames-terminal).

2. To see the names and statuses of all containers, run the command:
   ```bash
   docker ps -a
   ```

   :::tip

   Command-line options are described in the the `docker ps` command's [documentation](https://docs.docker.com/reference/cli/docker/container/ls/).

   :::

3. To see the logs of a container with name `{name}`, run the command:
   ```bash
   docker logs {name}
   ```
   For example, to see the logs of container `infra_caddy-ingress-http-1`, run the command:
   ```bash
   docker logs infra_caddy-ingress-http-1
   ```

   :::tip

   Command-line options are described in the the `docker logs` command's [documentation](https://docs.docker.com/reference/cli/docker/container/logs/).

   :::

## How to check systemd service status

### via Cockpit

1. [Open Cockpit](../day-1/sw-access/README.md#cockpit).
2. If Cockpit's top menubar displays a yellow lock icon with the label "Limited access", click on it to enable administrative access.
3. Open the "Services" page using Cockpit's navigation sidebar.
4. Click on the entry for the service.

### via the terminal

1. [Enter the RPi's terminal](../day-1/sw-access/README.md#the-frames-terminal).
2. To see the status of a service with name `{name}.service`, run the command:
   ```bash
   systemctl status {name}.service
   ```
   For example, to see the status of service `ssh.service`, run the command:
   ```bash
   systemctl status ssh.service
   ```

   :::tip

   Command-line options are described in the the `systemctl status` command's [documentation](https://www.freedesktop.org/software/systemd/man/latest/systemctl.html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).

   :::

3. To see the logs of the service with name `{name}.service`, run the command:
   ```bash
   journalctl -u {name}.service
   ```
   For example, to see the logs of service `ssh.service`, run the command:
   ```bash
   journalctl -u ssh.service
   ```

   :::tip

   Command-line options are described in the the `journalctl` command's [documentation](https://www.freedesktop.org/software/systemd/man/latest/journalctl.html).

   :::

## How to check network port bindings

1. [Enter the RPi's terminal](../day-1/sw-access/README.md#the-frames-terminal).
2. Run the command:
   ```bash
   sudo netstat -tulpn
   ```

   :::tip

   Command-line options are described in the the `netstat` command's [documentation](https://manpages.debian.org/stable/net-tools/netstat.8.en.html).

   :::

## How to check firewall settings

### via Cockpit

1. [Open Cockpit](../day-1/sw-access/README.md#cockpit).
2. If Cockpit's top menubar displays a yellow lock icon with the label "Limited access", click on it to enable administrative access.
3. Open the "Networking" page using Cockpit's navigation sidebar.
4. In the "Firewall" page, click on the "Edit rules and zones" button.

### via the terminal

1. [Enter the RPi's terminal](../day-1/sw-access/README.md#the-frames-terminal).
2. Run the commands:
   ```bash
   sudo firewall-cmd --list-all --zone=public
   sudo firewall-cmd --list-all --zone=nm-shared
   ```

   :::tip

   Command-line options are described in the the `firewall-cmd` command's [documentation](https://firewalld.org/documentation/man-pages/firewall-cmd.html).

   :::

## How to open a new firewall port

### temporarily

#### via Cockpit

1. [Open Cockpit](../day-1/sw-access/README.md#cockpit).
2. If Cockpit's top menubar displays a yellow lock icon with the label "Limited access", click on it to enable administrative access.
3. Open the "Networking" page using Cockpit's navigation sidebar.
4. In the "Firewall" page, click on the "Edit rules and zones" button.
5. If the port needs to be accessible over [direct connections to the FRAME](../day-1/connectivity/README.md#directly), add a firewalld service for the port in the "NetworkManager Shared" zone:
   1. In the "NetworkManager Shared zone" section, click on the "Add services" button to create a new firewalld service.
   2. In the resulting modal dialogue, either:
      - Click on the "Services" radio button, select a known service associated with the port, and then click on the "Add services" button; or
      - Click on the "Custom ports" radio button, enter the requested information, and then click on the "Add ports" button.
6. If the port needs to be accessible over indirect connections to the FRAME [via a Local Area Network](../day-1/connectivity/README.md#via-a-local-area-network), add a firewall service for the port in the "Public" zone:
   1. In the "Public zone" section, click on the "Add services" button to create a new firewalld service.
   2. In the resulting modal dialogue, either:
      - Click on the "Services" radio button, select a known service associated with the port, and then click on the "Add services" button; or
      - Click on the "Custom ports" radio button, enter the requested information, and then click on the "Add ports" button.

#### via the terminal

To open up a new TCP port `{port}`:

1. [Enter the RPi's terminal](../day-1/sw-access/README.md#the-frames-terminal).
2. Run the commands:
   ```bash
   sudo firewall-cmd --zone=public    --add-port={port}/tcp
   sudo firewall-cmd --zone=nm-shared --add-port={port}/tcp
   ```
   For example, to open up TCP port 8080, run:
   ```bash
   sudo firewall-cmd --zone=public    --add-port=8080/tcp
   sudo firewall-cmd --zone=nm-shared --add-port=8080/tcp
   ```

   :::tip

   Command-line options are described in the the `firewall-cmd` command's [documentation](https://firewalld.org/documentation/man-pages/firewall-cmd.html).

   :::

### persistently

To open up a new port `{port}` in protocol `{protocol}`:

1. [Enter the RPi's terminal](../day-1/sw-access/README.md#the-frames-terminal).
2. If the port needs to be accessible over [direct connections to the FRAME](../day-1/connectivity/README.md#directly), add a rule for the port in the "nm-shared" zone:
   1. Run the following command:
      ```bash
      sudo tee -a <<<'  <port port="{port}" protocol="{protocol}"/>' \
         /etc/firewalld/zones.d/nm-shared/80-custom-ports.xml
      ```
      For example, to open up TCP port 8080, run:
      ```bash
      sudo tee -a <<<'  <port port="8080" protocol="tcp"/>' \
         /etc/firewalld/zones.d/nm-shared/80-custom-ports.xml
      ```
3. If the port needs to be accessible over indirect connections to the FRAME [via a Local Area Network](../day-1/connectivity/README.md#via-a-local-area-network), add a rule for the port in the "public" zone:
   1. Run the following command:
      ```bash
      sudo tee -a <<<'  <port port="{port}" protocol="{protocol}"/>' \
         /etc/firewalld/zones.d/public/80-custom-ports.xml
      ```
      For example, to open up TCP port 8080, run:
      ```bash
      sudo tee -a <<<'  <port port="8080" protocol="tcp"/>' \
         /etc/firewalld/zones.d/public/80-custom-ports.xml
      ```
4. Apply your changes by rebooting or running the following commands:
   ```bash
   sudo systemctl restart \
      assemble-firewalld-zone@public.service \
      assemble-firewalld-zone@nm-shared.service
   sudo firewall-cmd --reload
   ```

:::info

`firewall-cmd`'s `--permanent` and `--runtime-to-permanent` options do not persist firewall configuration changes in openUC2 OS.
Instead, you **must** create files in openUC2 OS's drop-in configuration directories at `/etc/firewalld/zones.d/{zone name}`, as shown above.

:::

To undo this change:
1. [Enter the RPi's terminal](../day-1/sw-access/README.md#the-frames-terminal).
2. Run the following command:
   ```bash
   sudo sed -i '/<port port="{port}" protocol="tcp"/>/d' \
      /etc/firewalld/zones.d/public/80-custom-ports.xml \
      /etc/firewalld/zones.d/nm-shared/80-custom-ports.xml
   ```
   For example, to undo the opening of TCP port 8080, run:
   ```bash
   sudo sed -i '/<port port="8080" protocol="tcp"/>/d' \
      /etc/firewalld/zones.d/public/80-custom-ports.xml \
      /etc/firewalld/zones.d/nm-shared/80-custom-ports.xml
   ```
3. Apply your changes by rebooting or running the following commands:
   ```bash
   sudo systemctl restart \
      assemble-firewalld-zone@public.service \
      assemble-firewalld-zone@nm-shared.service
   sudo firewall-cmd --reload
   ```

## How to disable the firewall

:::danger

If your FRAME is connected to a Local Area Network (e.g. for internet access), this could allow anyone on the same network to do whatever they want with your FRAME!
You should ensure that:
- The network has its own firewall settings to prevent people you don't trust from using the network to access your FRAME (including over ports 80 and 443 for various administrative browser apps, and port 9090 for Cockpit).
- Your FRAME has a secure [password for the `pi` user](../day-1/security/README.md#how-to-change-the-pi-users-password), because it can be used for remotely [accessing the RPi's terminal](../day-1/sw-access/README.md#the-frames-terminal).

:::

### temporarily

#### via Cockpit

1. [Open Cockpit](../day-1/sw-access/README.md#cockpit).
2. If Cockpit's top menubar displays a yellow lock icon with the label "Limited access", click on it to enable administrative access.
3. Open the "Networking" page using Cockpit's navigation sidebar.
4. In the "Firewall" section, click on the "Enabled/Disabled" toggle.

#### via the terminal

To disable the firewall until the next boot:

1. [Enter the RPi's terminal](../day-1/sw-access/README.md#the-frames-terminal).
2. Run the command `sudo systemctl stop firewalld`.

To undo this change:

1. [Enter the RPi's terminal](../day-1/sw-access/README.md#the-frames-terminal).
2. Run the command `sudo systemctl start firewalld`.

### persistently

#### via Cockpit

1. [Open Cockpit](../day-1/sw-access/README.md#cockpit).
2. If Cockpit's top menubar displays a yellow lock icon with the label "Limited access", click on it to enable administrative access.
3. Open the "Services" page using Cockpit's navigation sidebar.
4. Click on the "firewalld" service entry to open the firewalld service management page.
5. Click on the "Start and enable/Stop and disable" toggle to change it to the disabled state.
6. In the menu next to the "Start and enable/Stop and disable" toggle, click on the "Disallow running (mask)" menu item.

#### via the terminal

To disable the firewall on every boot:

1. [Enter the RPi's terminal](../day-1/sw-access/README.md#the-frames-terminal).
2. Run the command `sudo systemctl disable --now firewalld`.
3. Run the command `sudo systemctl mask firewalld`.

To undo this change:

1. [Enter the RPi's terminal](../day-1/sw-access/README.md#the-frames-terminal).
2. Run the command `sudo systemctl enable --now firewalld`.
3. Run the command `sudo systemctl unmask firewalld`.

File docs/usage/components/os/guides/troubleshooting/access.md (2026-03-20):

---
toc_max_heading_level: 4
---

# Software Access

The how-to guides here will help you to determine why you can't access a particular software program which is supposed to be running in openUC2 OS.

## How to troubleshoot an inaccessible network service

1. If the network service is deployed as a Docker container, [check the status of its Docker container(s)](#how-to-check-docker-container-status).

   Otherwise, if the network service is deployed as a systemd service, [check the status of its systemd service(s)](#how-to-check-systemd-service-status).

3. If the network service is supposed to be accessed via port 80, 443, or 8000, check whether other network services (e.g. ImSwitch, the openUC2 offline documentation, and the system file manager) are available over those ports by [opening their browser apps](../day-1/access.md#browser-apps).

4. If the network service binds directly to a port on the machine, [check the network port bindings](#how-to-check-network-port-bindings) to determine whether the network service is bound to its expected port.

   If not the network service is not bound to its expected port, check whether some other network service is already bound to the network port.

5. Check whether the network service is accessible over a local connection from within the machine (i.e. as `localhost`).

6. [Check the firewall settings](#how-to-check-firewall-settings) on the machine to determine whether the firewall is configured to make the network service (and any network ports which it binds to) accessible over external network connections.

   If not, [open the port in the firewall](#how-to-open-a-new-firewall-port).
   If opening the firewall port doesn't seem to help, then check whether [disabling the firewall](#how-to-disable-the-firewall) makes the port accessible.
   If the port becomes accessible after disabling the firewall, then you have not correctly opened the port in the firewall.

## How to check Docker container status

### via Dozzle

1. [Open the browser app](../day-1/access.md#browser-apps) for Dozzle.
2. If the Docker container does not appear in the sidebar's list of running containers, then either the container has stopped or it never started.
   In that case, open the settings menu in the sidebar; if the "Show All Containers" menu item doesn't show a checked checkbox to indicate that it's enabled, click on that menu item to make Dozzle show all containers. If the Docker container then appears with a red circle, then the container has stopped.
3. Click on the container in the sidebar to see its logs.

### via the terminal

1. [Enter the machine's terminal](../day-1/access.md#the-machines-terminal).

2. To see the names and statuses of all containers, run the command:
   ```bash
   docker ps -a
   ```

   :::tip

   Command-line options are described in the the `docker ps` command's [documentation](https://docs.docker.com/reference/cli/docker/container/ls/).

   :::

3. To see the logs of a container with name `{name}`, run the command:
   ```bash
   docker logs {name}
   ```
   For example, to see the logs of container `infra_caddy-ingress-http-1`, run the command:
   ```bash
   docker logs infra_caddy-ingress-http-1
   ```

   :::tip

   Command-line options are described in the the `docker logs` command's [documentation](https://docs.docker.com/reference/cli/docker/container/logs/).

   :::

## How to check systemd service status

### via Cockpit

1. [Open Cockpit](../day-1/access.md#cockpit).
2. If Cockpit's top menubar displays a yellow lock icon with the label "Limited access", click on it to enable administrative access.
3. Open the "Services" page using Cockpit's navigation sidebar.
4. Click on the entry for the service.

### via the terminal

1. [Enter the machine's terminal](../day-1/access.md#the-machines-terminal).
2. To see the status of a service with name `{name}.service`, run the command:
   ```bash
   systemctl status {name}.service
   ```
   For example, to see the status of service `ssh.service`, run the command:
   ```bash
   systemctl status ssh.service
   ```

   :::tip

   Command-line options are described in the the `systemctl status` command's [documentation](https://www.freedesktop.org/software/systemd/man/latest/systemctl.html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).

   :::

3. To see the logs of the service with name `{name}.service`, run the command:
   ```bash
   journalctl -u {name}.service
   ```
   For example, to see the logs of service `ssh.service`, run the command:
   ```bash
   journalctl -u ssh.service
   ```

   :::tip

   Command-line options are described in the the `journalctl` command's [documentation](https://www.freedesktop.org/software/systemd/man/latest/journalctl.html).

   :::

## How to check network port bindings

1. [Enter the machine's terminal](../day-1/access.md#the-machines-terminal).
2. Run the command:
   ```bash
   sudo netstat -tulpn
   ```

   :::tip

   Command-line options are described in the the `netstat` command's [documentation](https://manpages.debian.org/stable/net-tools/netstat.8.en.html).

   :::

## How to check firewall settings

### via Cockpit

1. [Open Cockpit](../day-1/access.md#cockpit).
2. If Cockpit's top menubar displays a yellow lock icon with the label "Limited access", click on it to enable administrative access.
3. Open the "Networking" page using Cockpit's navigation sidebar.
4. In the "Firewall" page, click on the "Edit rules and zones" button.

### via the terminal

1. [Enter the machine's terminal](../day-1/access.md#the-machines-terminal).
2. Run the commands:
   ```bash
   sudo firewall-cmd --list-all --zone=public
   sudo firewall-cmd --list-all --zone=nm-shared
   ```

   :::tip

   Command-line options are described in the the `firewall-cmd` command's [documentation](https://firewalld.org/documentation/man-pages/firewall-cmd.html).

   :::

## How to open a new firewall port

### temporarily

#### via Cockpit

1. [Open Cockpit](../day-1/access.md#cockpit).
2. If Cockpit's top menubar displays a yellow lock icon with the label "Limited access", click on it to enable administrative access.
3. Open the "Networking" page using Cockpit's navigation sidebar.
4. In the "Firewall" page, click on the "Edit rules and zones" button.
5. If the port needs to be accessible over [direct connections to the machine](../day-1/connectivity.md#directly), add a firewalld service for the port in the "NetworkManager Shared" zone:
   1. In the "NetworkManager Shared zone" section, click on the "Add services" button to create a new firewalld service.
   2. In the resulting modal dialogue, either:
      - Click on the "Services" radio button, select a known service associated with the port, and then click on the "Add services" button; or
      - Click on the "Custom ports" radio button, enter the requested information, and then click on the "Add ports" button.
6. If the port needs to be accessible over indirect connections to the machine [via a LAN](../day-1/connectivity.md#via-a-lan), add a firewall service for the port in the "Public" zone:
   1. In the "Public zone" section, click on the "Add services" button to create a new firewalld service.
   2. In the resulting modal dialogue, either:
      - Click on the "Services" radio button, select a known service associated with the port, and then click on the "Add services" button; or
      - Click on the "Custom ports" radio button, enter the requested information, and then click on the "Add ports" button.

#### via the terminal

To open up a new TCP port `{port}`:

1. [Enter the machine's terminal](../day-1/access.md#the-machines-terminal).
2. Run the commands:
   ```bash
   sudo firewall-cmd --zone=public    --add-port={port}/tcp
   sudo firewall-cmd --zone=nm-shared --add-port={port}/tcp
   ```
   For example, to open up TCP port 8080, run:
   ```bash
   sudo firewall-cmd --zone=public    --add-port=8080/tcp
   sudo firewall-cmd --zone=nm-shared --add-port=8080/tcp
   ```

   :::tip

   Command-line options are described in the the `firewall-cmd` command's [documentation](https://firewalld.org/documentation/man-pages/firewall-cmd.html).

   :::

### persistently

To open up a new port `{port}` in protocol `{protocol}`:

1. [Enter the machine's terminal](../day-1/access.md#the-machines-terminal).
2. If the port needs to be accessible over [direct connections to the machine](../day-1/connectivity.md#directly), add a rule for the port in the "nm-shared" zone:
   1. Run the following command:
      ```bash
      sudo tee -a <<<'  <port port="{port}" protocol="{protocol}"/>' \
         /etc/firewalld/zones.d/nm-shared/80-custom-ports.xml
      ```
      For example, to open up TCP port 8080, run:
      ```bash
      sudo tee -a <<<'  <port port="8080" protocol="tcp"/>' \
         /etc/firewalld/zones.d/nm-shared/80-custom-ports.xml
      ```
3. If the port needs to be accessible over indirect connections to the machine [via a LAN](../day-1/connectivity.md#via-a-lan), add a rule for the port in the "public" zone:
   1. Run the following command:
      ```bash
      sudo tee -a <<<'  <port port="{port}" protocol="{protocol}"/>' \
         /etc/firewalld/zones.d/public/80-custom-ports.xml
      ```
      For example, to open up TCP port 8080, run:
      ```bash
      sudo tee -a <<<'  <port port="8080" protocol="tcp"/>' \
         /etc/firewalld/zones.d/public/80-custom-ports.xml
      ```
4. Apply your changes by rebooting, soft-rebooting, or running the following commands:
   ```bash
   sudo systemctl restart \
      assemble-firewalld-zone@public.service \
      assemble-firewalld-zone@nm-shared.service
   sudo firewall-cmd --reload
   ```

:::info

`firewall-cmd`'s `--permanent` and `--runtime-to-permanent` options do not persist firewall configuration changes in openUC2 OS.
Instead, you **must** create files in openUC2 OS's drop-in configuration directories at `/etc/firewalld/zones.d/{zone name}`, as shown above.

:::

To undo this change:
1. [Enter the machine's terminal](../day-1/access.md#the-machines-terminal).
2. Run the following command:
   ```bash
   sudo sed -i '/<port port="{port}" protocol="tcp"/>/d' \
      /etc/firewalld/zones.d/public/80-custom-ports.xml \
      /etc/firewalld/zones.d/nm-shared/80-custom-ports.xml
   ```
   For example, to undo the opening of TCP port 8080, run:
   ```bash
   sudo sed -i '/<port port="8080" protocol="tcp"/>/d' \
      /etc/firewalld/zones.d/public/80-custom-ports.xml \
      /etc/firewalld/zones.d/nm-shared/80-custom-ports.xml
   ```
3. Apply your changes by rebooting, soft-rebooting, or running the following commands:
   ```bash
   sudo systemctl restart \
      assemble-firewalld-zone@public.service \
      assemble-firewalld-zone@nm-shared.service
   sudo firewall-cmd --reload
   ```

## How to disable the firewall

:::danger

If your machine is connected to a LAN (e.g. for internet access), this could allow anyone on the same network to do whatever they want with your machine!
You should ensure that:
- The network has its own firewall settings to prevent people you don't trust from using the network to access your machine (including over ports 80 and 443 for various administrative browser apps, and port 9090 for Cockpit).
- Your machine has a secure [password for the `pi` user](../day-1/security.md#how-to-change-the-pi-users-password), because it can be used for remotely [accessing the machine's terminal](../day-1/access.md#the-machines-terminal).

:::

### temporarily

#### via Cockpit

1. [Open Cockpit](../day-1/access.md#cockpit).
2. If Cockpit's top menubar displays a yellow lock icon with the label "Limited access", click on it to enable administrative access.
3. Open the "Networking" page using Cockpit's navigation sidebar.
4. In the "Firewall" section, click on the "Enabled/Disabled" toggle.

#### via the terminal

To disable the firewall until the next boot:

1. [Enter the machine's terminal](../day-1/access.md#the-machines-terminal).
2. Run the command `sudo systemctl stop firewalld`.

To undo this change:

1. [Enter the machine's terminal](../day-1/access.md#the-machines-terminal).
2. Run the command `sudo systemctl start firewalld`.

### persistently

#### via Cockpit

1. [Open Cockpit](../day-1/access.md#cockpit).
2. If Cockpit's top menubar displays a yellow lock icon with the label "Limited access", click on it to enable administrative access.
3. Open the "Services" page using Cockpit's navigation sidebar.
4. Click on the "firewalld" service entry to open the firewalld service management page.
5. Click on the "Start and enable/Stop and disable" toggle to change it to the disabled state.
6. In the menu next to the "Start and enable/Stop and disable" toggle, click on the "Disallow running (mask)" menu item.

#### via the terminal

To disable the firewall on every boot:

1. [Enter the machine's terminal](../day-1/access.md#the-machines-terminal).
2. Run the command `sudo systemctl disable --now firewalld`.
3. Run the command `sudo systemctl mask firewalld`.

To undo this change:

1. [Enter the machine's terminal](../day-1/access.md#the-machines-terminal).
2. Run the command `sudo systemctl enable --now firewalld`.
3. Run the command `sudo systemctl unmask firewalld`.

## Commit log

2026-03-11 Add firewall-related how-to guides & reference guide (#39)
    This PR provides some concrete illustrations of the [Diátaxis
    approach](https://diataxis.fr/) to documentation by adding how-to guides
    related to the firewall and a reference guide related to the firewall.
    Note: in the future, it might make sense to move some of these how-to
    guides out of the FRAME product docs and into the openUC2 OS docs
    instead. But only the FRAME uses openUC2 OS right now, so I won't worry
    about this for now.
2026-03-11 Move OS docs into their own section (#41)
    This PR moves various how-to guides for the usage of openUC2 OS from the
    FRAME usage docs into the openUC2 OS usage docs.
2026-03-14 adding docs for master insert
    [PRT - 2100 - MASINS - V04 - B.stp, PRT - 2123 - MASLCK - V04 - B.stp, PRT - 2129 - MASINSLEND16F44.5 - A.stp]
2026-03-16 Add some FRAME day-1 tutorials (#44)
    This PR adds day-1 tutorials for accessing ImSwitch and for enabling
    remote assistance.
    This work is tracked on Notion at
    https://www.notion.so/Publish-draft-Day-1-docs-for-customers-3064e612c78a80c5a6e2ec59ade2344d?source=copy_link
2026-03-17 Add remaining draft FRAME day-1 tutorials (#45)
    This PR adds day-1 tutorials for doing stuff inside ImSwitch.
    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
2026-03-23 adding lens maker
2026-03-24 Add guides for device-admin's reboot & shutdown GUI functionality (#48)
    This PR adds how-to guides for
    https://github.com/openUC2/device-admin/pull/38, which was integrated
    into openUC2 OS in https://github.com/openUC2/os-rpi/pull/175 .
2026-03-24 Add day-1 tutorial for shutting down the FRAME (#49)
    This PR follows up on #48 by adding a FRAME day-1 tutorial for using
    device-admin to shut down the FRAME safely.
2026-03-25 Add day-1 tutorial for inserting & positioning the first sample (#50)
    This PR adds some missing sections of the day-1 "first sample" tutorial.
    https://www.notion.so/Publish-first-draft-of-Day-1-docs-for-customers-3064e612c78a80c5a6e2ec59ade2344d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
2026-03-27 Add guide for changing Wi-Fi hotspot password via device-admin (#52)
    This PR adds a how-to usage guide for the functionality added by
    https://github.com/openUC2/device-admin/pull/41 .
    https://www.notion.so/Support-changing-the-Wi-Fi-hotspot-password-from-the-Machine-Admin-app-3224e612c78a809cbebcdb052a8545de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
2026-04-02 build(ci): bump the ci group with 8 updates (#57)
    Bumps the ci group with 8 updates:
    | Package | From | To |
    | --- | --- | --- |
    |
    [ASzc/change-string-case-action](https://github.com/aszc/change-string-case-action)
    | `6` | `8` |
    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
2026-05-11 build(npm): bump fast-uri from 3.1.0 to 3.1.2 (#65)
    Bumps [fast-uri](https://github.com/fastify/fast-uri) from 3.1.0 to
    3.1.2.
    <details>
    <summary>Release notes</summary>
    <p><em>Sourced from <a
    href="https://github.com/fastify/fast-uri/releases">fast-uri's
    releases</a>.</em></p>
    <blockquote>
    <h2>v3.1.2</h2>
    <h2>⚠️ Security Release</h2>
    <ul>
    <li>Fix for <a
    href="https://github.com/fastify/fast-uri/security/advisories/GHSA-v39h-62p7-jpjc">https://github.com/fastify/fast-uri/security/advisories/GHSA-v39h-62p7-jpjc</a></li>
    </ul>
    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
2026-05-31 adding frame objective holder
2026-05-31 adding odmr flow chart
2026-06-04 Improve tutorial for safe shutdown of the FRAME (#70)
    This PR improves the FRAME's day-1 Safe Shutdown tutorial in order to
    hopefully make the OS shutdown process's UX slightly less surprising, by
    explaining what the user should expect to see during the process.
    This work is tracked in
    https://app.notion.com/p/TASK-FR014-Bug-ImSwitch-is-unable-to-shut-down-the-RPi-30a4e612c78a808db81efe5f053fcc93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
2026-06-16 Update instructions for openUC2/os-rpi#252 (#72)
    This PR updates the day-1 guides & tutorials based on improvements made
    in https://github.com/openUC2/os-rpi/pull/252 to the usability of
    `.local` domain names in Windows client devices.
2026-08-02 build(npm): bump postcss from 8.5.6 to 8.5.25 (#80)
    Bumps [postcss](https://github.com/postcss/postcss) from 8.5.6 to
    8.5.25.
    href="https://github.com/postcss/postcss/releases">postcss's
    <h2>8.5.25</h2>
    <li>Fixed 8.5.17 visitor regression.</li>
    <li>Fixed <code>list.split()</code> for non-string values (by <a
    href="https://github.com/amir-rezaei"><code>@ amir-rezaei</code></a>).</li>
    <h2>8.5.24</h2>
    <li>Preserve the BOM after the processing (by <a
    href="https://github.com/hdimer"><code>@ hdimer</code></a>).</li>
    <h2>8.5.23</h2>
    <li>Do not load source map without
    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
2026-08-02 build(npm): bump fast-uri from 3.1.2 to 3.1.5 (#84)
    Bumps [fast-uri](https://github.com/fastify/fast-uri) from 3.1.2 to
    3.1.5.
    <h2>v3.1.5</h2>
    <h2>⚠️ Security Warning</h2>
    <p>Fix for <a
    href="https://github.com/fastify/fast-uri/security/advisories/GHSA-7p8r-x3mc-p8w7">https://github.com/fastify/fast-uri/security/advisories/GHSA-7p8r-x3mc-p8w7</a></p>
    <p><strong>Full Changelog</strong>: <a
    href="https://github.com/fastify/fast-uri/compare/v3.1.4...v3.1.5">https://github.com/fastify/fast-uri/compare/v3.1.4...v3.1.5</a></p>
    <h2>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
2026-08-02 Add more CoreBOX docs & FRAME tutorials (#77)
2026-08-10 Add more FRAME documentation (#90)
    This PR duplicates and continues PR #77 , starting with
    [1531655](https://github.com/openUC2/docs/pull/90/commits/1531655946bd861b7c56ee3a518647f6d14a8a70).
    ---------
2026-09-03 build(npm): bump fast-uri from 3.1.5 to 3.1.7 (#94)
    Bumps [fast-uri](https://github.com/fastify/fast-uri) from 3.1.5 to
    3.1.7.
    <h2>v3.1.7</h2>
    <p>This is a security release that fixes the following high-severity
    security advisories:</p>
    <li><a
    href="https://github.com/fastify/fast-uri/security/advisories/GHSA-qw65-cvwx-89v3">GHSA-qw65-cvwx-89v3</a>
    — authority injection via an unvalidated port in
    <code>serialize()</code></li>
    <li><a
    href="https://github.com/fastify/fast-uri/security/advisor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
2026-11-11 adding calibration results from FRAME
2026-11-11 Updating first-time user instructions for FRAME
